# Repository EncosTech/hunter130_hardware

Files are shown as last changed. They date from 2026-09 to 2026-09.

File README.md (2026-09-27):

# Hunter V2 · 开源人形机器人硬件

> 快装快换，随心所造。

**Hunter V2** 是南京因克斯智能科技有限公司与桥介数物联合打造的开源人形机器人。因克斯负责硬件设计与制造，桥介数物负责软件开发，双方共同推进 Hunter 系列机器人的持续迭代。

本仓库 `hunter130_hardware` 提供 Hunter V2（EC H130-V2）的机械模型、电气资料、机器人描述文件和安装手册，供开发者开展结构研究、装配、仿真接入与二次开发。

## 项目亮点

- **第二代关节**：采用因克斯第二代关节模组，支持快速拆装，便于维护与更换。
- **25 个自由度**：覆盖躯干、双臂与双腿，为人形机器人的运动研究与开发提供硬件基础。
- **硬件与软件协作**：因克斯负责硬件，桥介数物负责部署与训练相关软件。
- **持续迭代**：延续 Hunter V1 的开源合作，继续更新 Hunter 系列机器人及配套资源。

## 基本参数

| 项目 | 规格 |
| --- | --- |
| 产品名称 | Hunter V2 |
| 硬件型号 | EC H130-V2 |
| 身高 | 130 cm |
| 整机重量 | 约 32 kg |
| 全身自由度 | 25 |
| 关节模组 | 因克斯第二代关节，支持快速拆装 |
| 硬件设计与制造 | 南京因克斯智能科技有限公司 |
| 软件开发 | 桥介数物 |

## 仓库内容

```text
hunter130_hardware/
├── Mechanical/                       # 机械模型与安装手册
│   ├── EC-H130-V2_装配体.STEP        # STEP 格式整机装配模型（Git LFS）
│   ├── EC-H130-V2_装配体.x_t         # Parasolid 格式整机装配模型（Git LFS）
│   └── EC H130-V2 产品安装手册.md
├── Electrical/                       # 电气资料
│   ├── Pcb/
│   │   ├── PMS/                      # PMS 板 PDF 与三维模型
│   │   ├── 胸腔电池安装板/            # 电池安装板 PDF 与三维模型
│   │   ├── 腿部电容板/                # 腿部电容板 PDF 与三维模型
│   │   └── 髋中心板/                  # 髋中心板 PDF 与三维模型
│   └── Wire/
│       ├── EC-H130线长.md             # 各部位线长、板卡与电阻要求
│       └── images/ec-h130-wire/       # 线束参考图片
├── URDF/                             # 机器人描述与网格资源
│   ├── EC-H130-V2_URDF.urdf
│   └── meshes/                       # STL 网格文件
├── LICENSE
└── README.md
```

| 资源 | 入口 | 内容 |
| --- | --- | --- |
| 安装手册 | [EC H130-V2 产品安装手册](Mechanical/EC%20H130-V2%20产品安装手册.md) | 装配注意事项、安装步骤、操作说明与物料清单 |
| 机械模型 | [STEP](Mechanical/EC-H130-V2_装配体.STEP) · [Parasolid](Mechanical/EC-H130-V2_装配体.x_t) | 两种格式的整机装配模型，均通过 Git LFS 下载 |
| 电气资料 | [Electrical/Pcb](Electrical/Pcb/) | PMS 板、胸腔电池安装板、腿部电容板和髋中心板的 PDF 与 STEP 文件 |
| 线束资料 | [EC-H130 线长](Electrical/Wire/EC-H130线长.md) | 各部位线长、电路板型号、电阻要求与线束参考图片 |
| 机器人描述 | [URDF](URDF/) | URDF 文件及其引用的 STL 网格资源 |

## 开始使用

### 下载完整模型

本仓库使用 [Git LFS](https://git-lfs.com/) 管理 STEP/STP、Parasolid（X_T/X_B）和 STL 模型，文件扩展名不区分大小写。请先安装 Git 和 Git LFS，再执行：

```bash
git lfs install
git clone https://github.com/EncosTech/hunter130_hardware.git
cd hunter130_hardware
git lfs pull
```

已有本地仓库时，在仓库目录执行 `git lfs install`、`git pull` 和 `git lfs pull`。使用 `git lfs ls-files` 可以查看由 LFS 管理的文件。

如果模型文件只有几行文本，并以 `version https://git-lfs.github.com/spec/v1` 开头，说明下载到的是 LFS 指针；请执行 `git lfs pull` 获取完整模型。GitHub 的 **Download ZIP** 是否包含模型原文件取决于仓库设置，建议使用上面的克隆方式。

### 使用资料

1. **了解结构与装配要求**：先阅读[安装手册](Mechanical/EC%20H130-V2%20产品安装手册.md)，了解装配流程、所需物料与安全操作要求。
2. **查看机械模型**：使用支持 STEP 或 Parasolid 的 CAD 工具打开 [Mechanical](Mechanical/) 中的模型。
3. **查看电气与线束资料**：按板卡类别查阅 [Electrical/Pcb](Electrical/Pcb/) 下的 PDF 与三维模型；线束制作与接线时，查阅 [EC-H130 线长](Electrical/Wire/EC-H130线长.md) 中的尺寸、板卡和电阻要求。
4. **接入仿真或可视化工具**：加载 [EC-H130-V2_URDF.urdf](URDF/EC-H130-V2_URDF.urdf)，并保留其与 `meshes/` 文件夹的相对位置。接入具体平台时，请按平台要求配置资源路径与控制接口。

## 软件与后续计划

本仓库聚焦硬件资料。部署程序与训练程序由桥介数物负责，作为配套软件开源内容持续更新；相关仓库链接将在公布后补充到此处。

后续计划兼容桥介 **RoboCraft AI** 平台，该项为规划内容。硬件资料与软件资源将随 Hunter 系列迭代持续完善。

## 反馈与贡献

欢迎通过 Issues 反馈资料问题、装配经验与改进建议，也欢迎提交 Pull Request 完善文档和设计资料。反馈时请注明硬件版本、相关文件路径，以及便于复现问题的说明或图片。

提交模型前，请在本地仓库执行 `git lfs install`。根目录的 `.gitattributes` 会自动将上述模型格式交给 LFS；按平常的 `git add`、`git commit`、`git push` 流程提交即可，推送时会同时上传 LFS 文件。新增其他大文件格式时，请先使用 `git lfs track` 配置追踪，并将更新后的 `.gitattributes` 一起提交。配置说明见 [GitHub 官方文档](https://docs.github.com/en/repositories/working-with-files/managing-large-files/configuring-git-large-file-storage)。

## 许可证

除另有说明的第三方材料外，本仓库由项目权利人提供的硬件设计文件、机器人描述文件及配套文档采用 **CERN Open Hardware Licence Version 2 – Strongly Reciprocal（CERN-OHL-S-2.0）** 授权。完整条款见 [LICENSE](LICENSE)。

SPDX-License-Identifier: CERN-OHL-S-2.0

允许依照许可证使用、复制、修改、制造和销售。对外分发相关设计或产品时，须履行许可证规定的完整源文件提供、声明保留和修改标注等义务；适用例外以许可证原文为准。

第三方材料遵循各自的许可证。本项目文档中的安全提示、产品使用说明和合规说明不构成对 CERN-OHL-S-2.0 授予权利的附加限制，也不赋予任何一方单方面更改该许可证的权利。

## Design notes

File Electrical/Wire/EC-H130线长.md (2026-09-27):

# EC-H130 线长

## 大腿

- 电源：200 mm。
- 信号：250 mm。

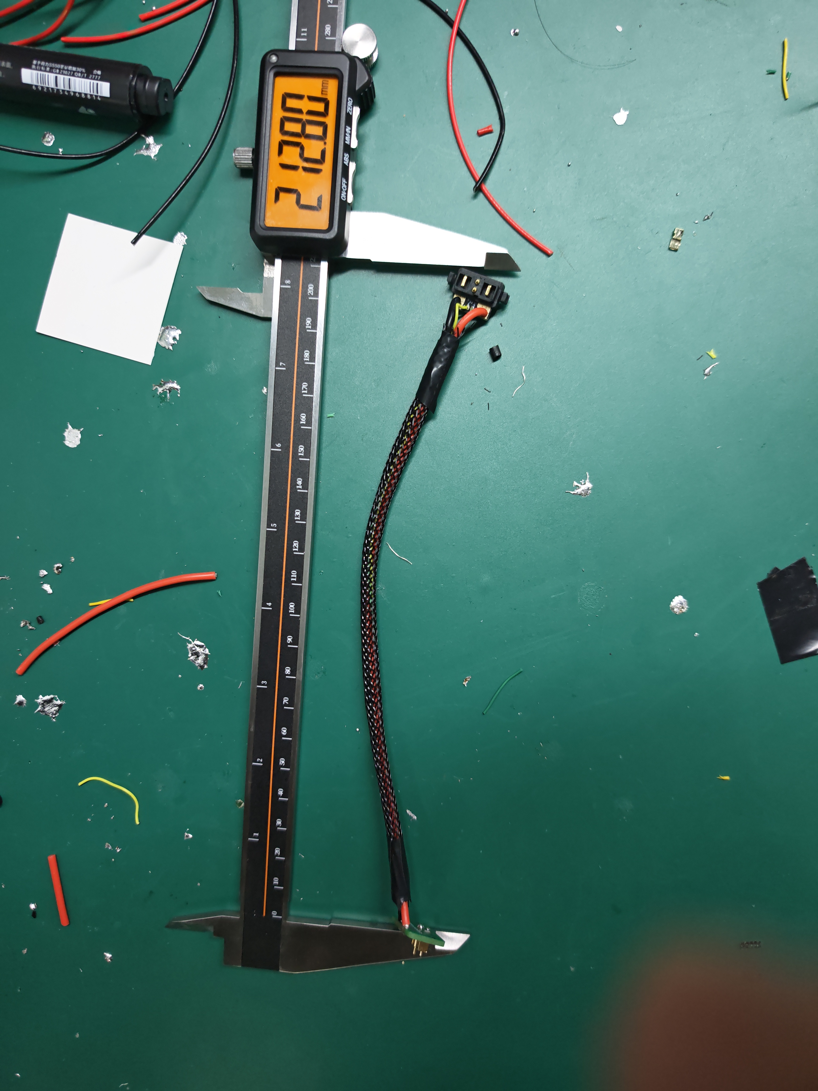
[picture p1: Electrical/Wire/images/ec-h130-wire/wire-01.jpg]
大腿线束


## 小臂

- 电源线：130 mm。

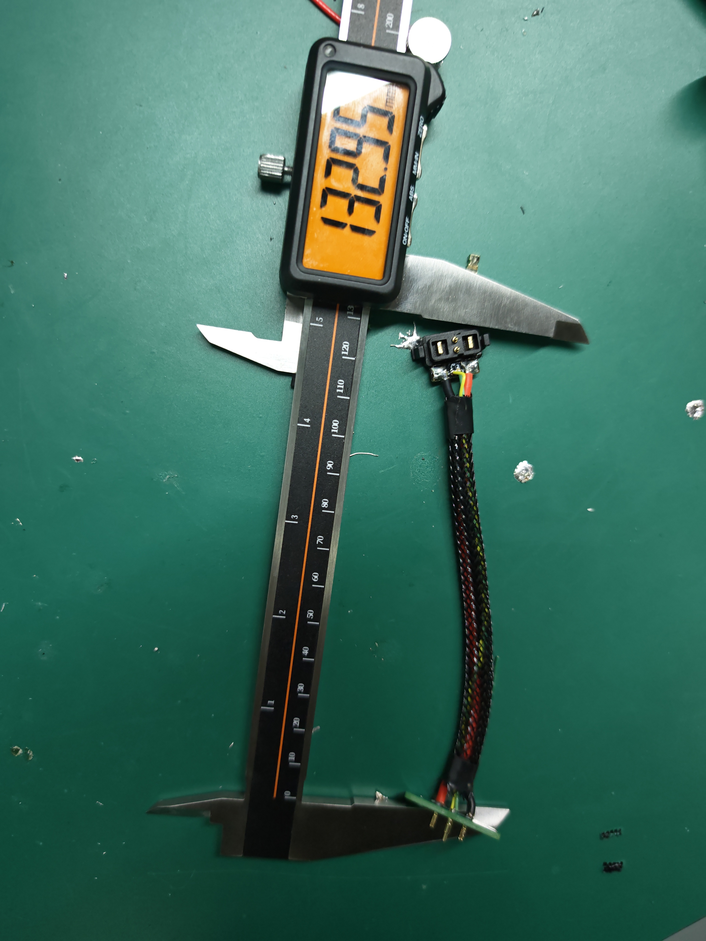
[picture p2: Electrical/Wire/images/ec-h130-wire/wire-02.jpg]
小臂线束


## 腿根

- 电路板：72xx。
- 线长：095 mm。

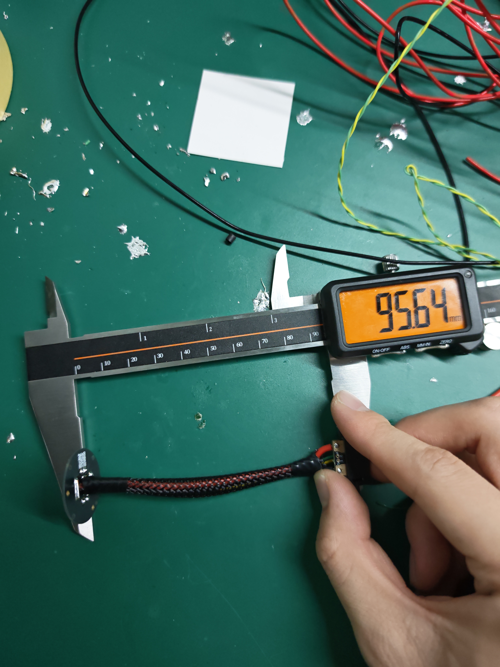
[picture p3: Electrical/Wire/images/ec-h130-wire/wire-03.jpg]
腿根线束


## 臂根

- 电路板：50xx。
- 线长：70 mm。

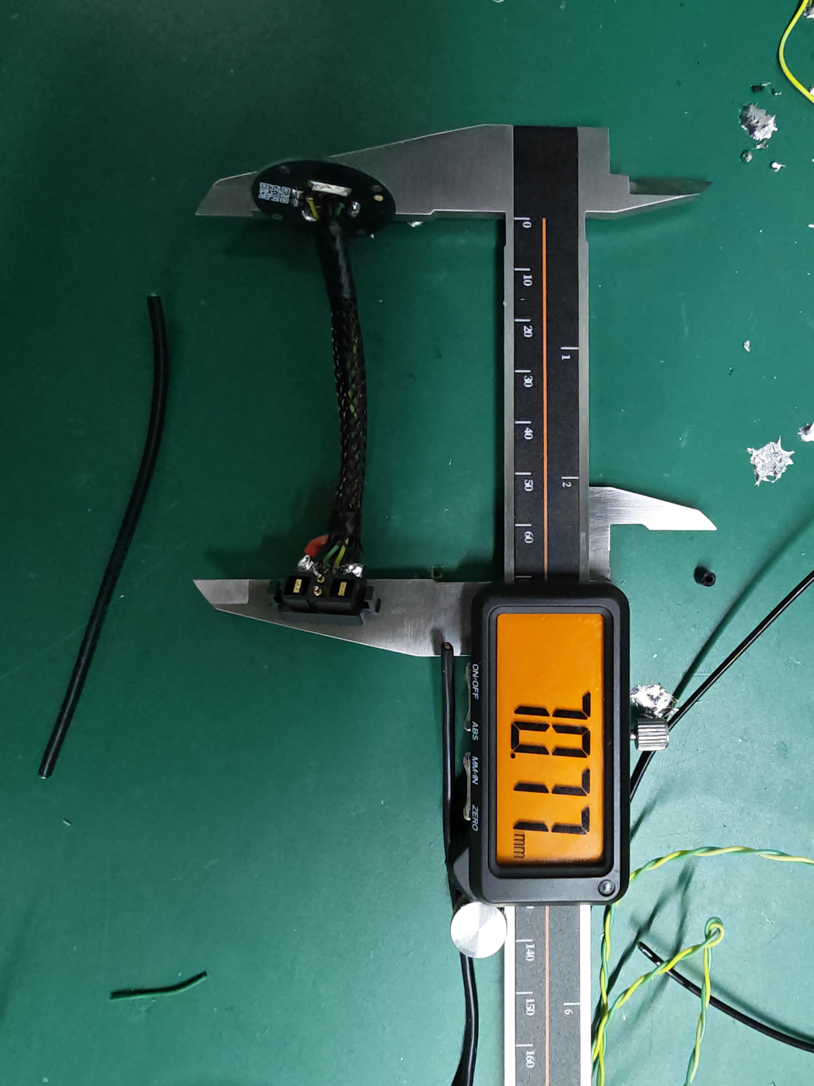
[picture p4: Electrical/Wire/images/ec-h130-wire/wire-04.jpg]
臂根线束


## 腿直角件 ×2

- 电路板：72xx。
- 线长：95 mm。

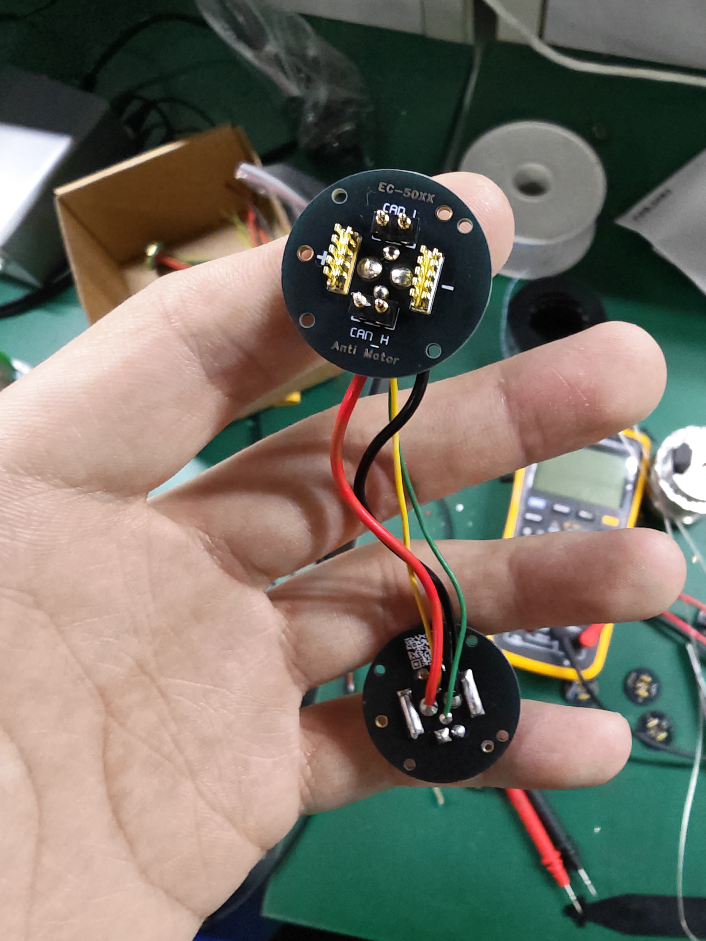
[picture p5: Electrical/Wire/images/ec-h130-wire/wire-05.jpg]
腿直角件线束


## 小腿双尾部

- 电源：200 mm。
- 信号线：203 mm。
- 需 120 Ω 电阻。

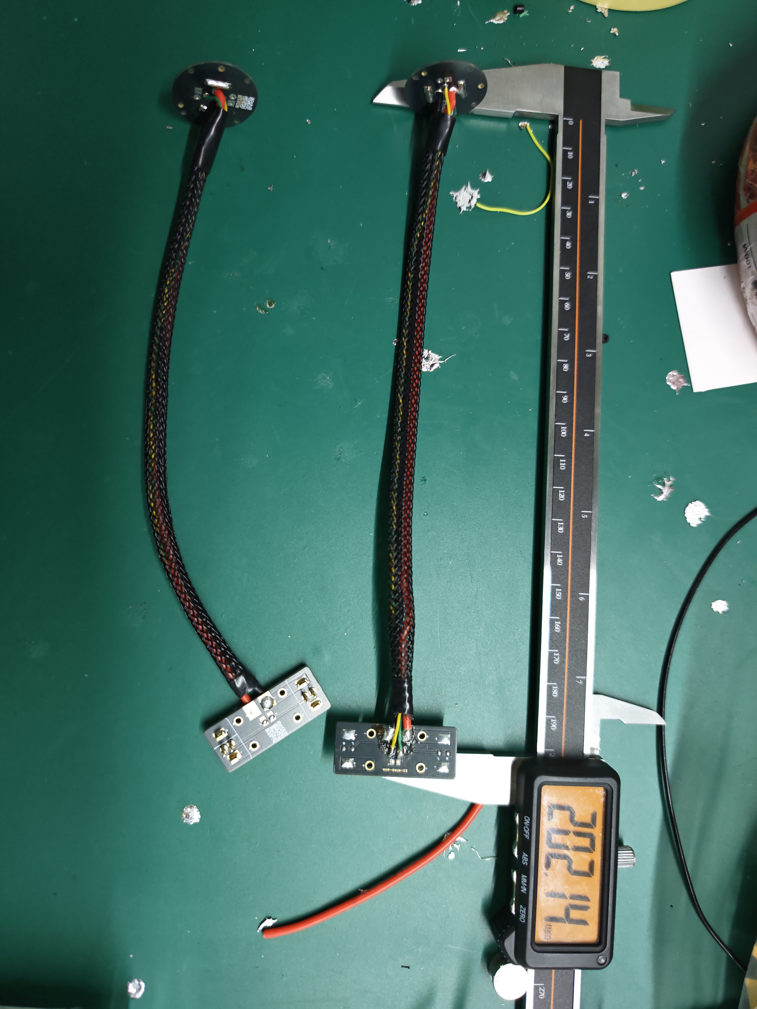
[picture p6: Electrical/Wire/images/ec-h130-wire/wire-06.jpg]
小腿双尾部线束


## 腰

- 线长：200 mm。
- 需 120 Ω 电阻。

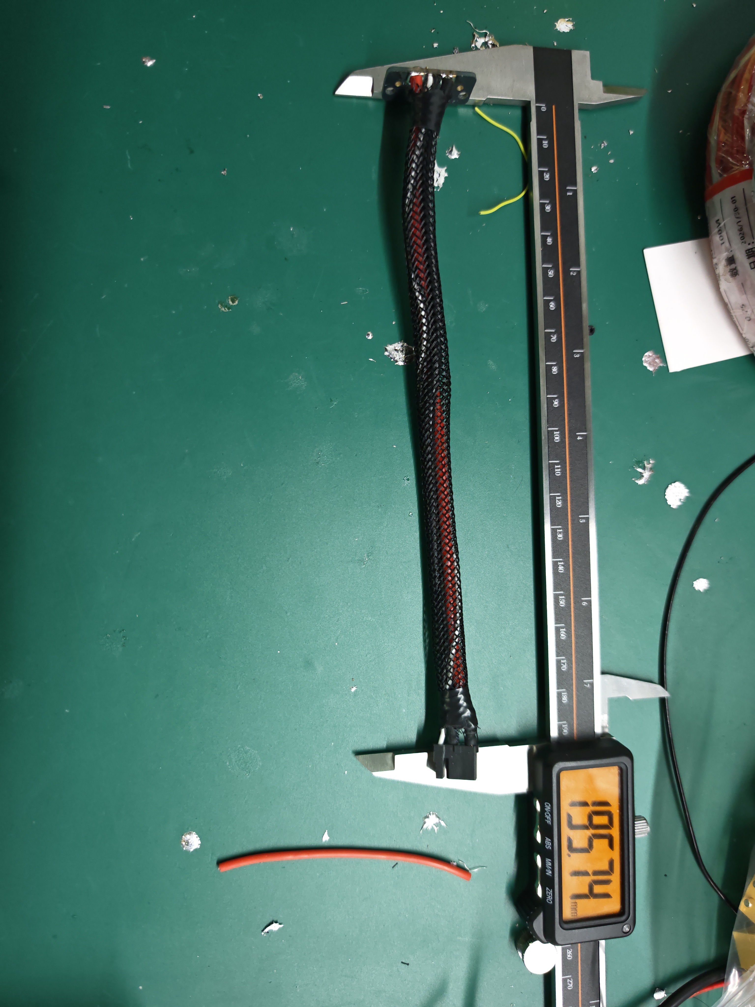
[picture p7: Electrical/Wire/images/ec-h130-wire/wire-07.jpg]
腰部线束


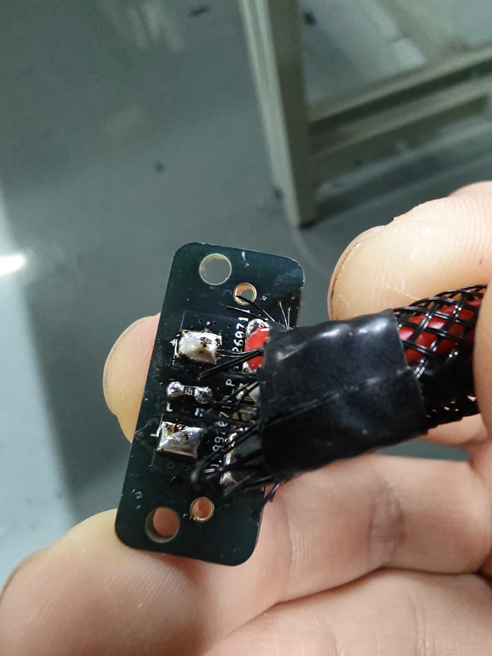
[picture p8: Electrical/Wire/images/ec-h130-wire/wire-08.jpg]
腰部接线板细节


## 左肩、右肩

- 线长：100 mm。
- 需 120 Ω 电阻。

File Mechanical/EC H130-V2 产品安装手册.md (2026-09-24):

# EC H130-V2 产品安装手册

> **开源许可证：CERN-OHL-S-2.0**  
> 本文档由项目权利人提供的内容采用 CERN Open Hardware Licence Version 2 – Strongly Reciprocal 授权，完整条款见仓库根目录的 [LICENSE](../LICENSE)。另有说明的第三方材料遵循各自许可证。  
> SPDX-License-Identifier: CERN-OHL-S-2.0  
> 本手册中的安全提示、产品使用说明、合规说明及“最终解释权”等表述，不构成对上述开源许可证授予权利的附加限制，也不赋予任何一方单方面更改该许可证的权利。适用法律规定的义务仍须遵守。

**EC H130-V2**

**产品安装手册**

南京因克斯智能科技有限公司

2026年9月

**目  录**

目录

1  安全及合规须知1

2  装配注意事项2

3  产品概述3

4  安装前置条件6

5  安装步骤7

6  安全操作指南17

附录A  主要零部件与辅料清单19

附录B  物料清单20

# 1  安全及合规须知

为避免违法行为、可能的伤害和损失，务必遵守以下各项规定：

1. 在使用本产品前，请务必仔细查阅本文档，以了解您的权益、责任以及安全事项；如未遵守可能导致财产损失或安全隐患。使用本产品即表示您已充分理解并接受本文件的所有条款，需严格按照规范操作，并对自身行为及相关后果负全责。

2. 本产品为非玩具类设备，不建议18岁以下人士使用。请防止儿童接触产品，在有儿童场景中操作时须特别谨慎。

3. 本产品不宜在人员密集区域使用，使用时需确保人员与机器距离保持在1米半径外。如因误操作对相关人员造成伤害或损失，南京因克斯智能科技有限公司不承担任何责任。

4. 本产品设计为接触地面使用，请勿在设备运动过程中抬起设备造成双腿离地。

5. 请勿在极端环境（如高温、低温、腐蚀性化学物质等）下使用本产品。因此类情况造成的设备问题，南京因克斯智能科技有限公司不承担任何责任。

6. 在正常使用条件下，因零部件自然磨损或电池老化导致的问题，不视为产品质量问题，南京因克斯智能科技有限公司对此不承担责任。

7. 本产品禁止用于任何危害国家安全的活动，包括但不限于恐怖主义支持、核设施、生化武器研发或大规模杀伤性武器的设计与使用等领域。

8. 您确认您未受任何贸易限制或制裁措施的影响，否则可能无法正常使用南京因克斯智能科技有限公司系列产品及服务。

9. 南京因克斯智能科技有限公司致力于确保产品在全球范围内合规。请遵守所在地区的法律法规，并注意相关合规要求。

10. 您需遵守适用地区的出口管制法律法规。

11. 您承诺将本产品用于正当用途，并同意接受本文件所有条款。

12. 在当地法律适用范围内，南京因克斯智能科技有限公司保留对本协议的最终解释权，并可能根据需要进行更新或调整。

注：现有手册基于当前 EC H130-V2 版本编制，因产品持续优化，后续批次的套件和文档可能存在微调，最新版本文档可在公司官网服务与支持页面查阅，最终解释权归属南京因克斯智能科技有限公司所有。

# 2  装配注意事项

## 2.1  工作台管理

### 2.1.1  分区摆放

（1）左侧：待装配物料区（仅放置当前工序所需物料）。

（2）中间：作业区（铺设防静电胶皮，保持清洁）。

（3）右侧：成品/半成品放置区。

### 2.1.2  异物防范

严禁在工作台上放置与生产无关的物品（如手机、水杯、钥匙），防止金属异物掉入产品内部造成短路。

## 2.2  个人防护装备标准

（1）防静电手套：接触所有电子元器件、电路板、摄像头模组时佩戴。

（2）丁腈手套：使用润滑脂、导热硅脂、螺纹胶、厌氧胶等化学品时佩戴。

（3）束发/着装强制：长发必须盘起并塞入工帽；严禁佩戴悬挂式首饰（项链、手链）；袖口需束紧。

## 2.3  核心安全作业规程

### 2.3.1  锂电池安全操作

本产品使用高能量密度锂电池组，操作不当极易引发火灾。

跌落处置：任何电池组一旦发生跌落（高度大于30cm）或受到剧烈撞击，严禁再次装机使用。必须立即贴上红色“待报废/观察”标签，并移至指定的防爆安全柜或沙箱中隔离观察24小时。

### 2.3.2  机械防夹与操作

（1）断电作业：关节的安装、调试与更换，必须在急停按下且断开电源的状态下进行。

（2）手动盘车：严禁将手指伸入关节活动的缝隙或限位槽内，防止关节因重力滑落或惯性闭合时造成手指挤压骨折。

（3）螺丝固定：拧平头螺丝时不宜用力过猛，以免造成滑丝。

### 2.3.3  化学品使用安全

（1）螺纹胶：仅涂抹于螺纹末端3—4牙处，严禁过量溢出污染塑料件（部分塑料遇螺纹胶会脆裂）。

（2）厌氧胶（如243）：用于螺钉防松，螺钉固定前按要求涂抹，注意控制用量。

（3）废弃物处理：沾染化学品的无尘布、棉签属于危险废弃物，必须丢弃至专门的黄色危废垃圾桶，严禁混入普通垃圾。

### 2.3.4  紧急响应流程

当发生异常情况（冒烟、起火、异响、人员受伤）时，严格遵循“停止—隔离—上报”流程。

电池/电路起火处置：

步骤一：立即按下总电源急停开关。

步骤二：人员迅速撤离至安全距离（大于3米），并大声示警。

步骤三：小火苗：使用干粉灭火器扑灭，严禁用水。

（4）大火：立即拨打火警电话并撤离车间。

# 3  产品概述

## 3.1  产品简介

EC H130-V2 是南京因克斯智能科技有限公司面向科研、教育以及展演场景推出的人形机器人平台。产品采用模块化关节模组与铝合金结构件设计，全身关节由多种规格的伺服模组驱动，覆盖躯干、腰部、双臂、髋部与双腿，结构紧凑，便于实验室调试、教学实验与工程验证。主要结构件采用铝合金加工，外观件通过3D打印快速成型，装配效率高、维护成本低。本手册依据产品当前版本的安装工序（SOP）编制，详细说明安装前置条件、安装步骤、检测方法与安全操作要求。

## 3.2 产品参数

| 无标题的项目 (2).jpg | **结构参数** |  |
| --- | --- | --- |
|  | 身高 | 130 cm |
|  | 自由度 | 25 |
|  | 体重 | 30kg |
|  | 结构件材质 | 航空铝+调制40cr |
|  | **电源与电池** |  |
|  | 电池类型 | 可充电锂离子电池 |
|  | 续航时长 | 3.5h（两块） |
|  | 标称电压 | 46.8V |
|  | 充电方式 | 充电器/cc-cv |
|  | BMS保护功能 | 限位/过流/过压保护 |

**3.3****安装说明**

在开始组装前，请根据下图电机ID布局，对所有电机进行ID分配与编码器校准；禁止大力敲击电机，防止损坏内部组件。



## 3.4  关节模组配置

EC H130-V2 全身共使用 25 个关节模组，配置如下表所示。

| **序号** | **模组型号** | **数量** | **用途说明** |
| --- | --- | --- | --- |
| 1 | EC-A5020-P2-17H-A | 6 | 手臂、肩部等关节 |
| 2 | EC-A5020-P2-17H-B | 8 | 手臂、腿部等关节 |
| 3 | EC-A7220-P2-22H-A | 4 | 大功率关节 |
| 4 | EC-A7220-P2-22H-B | 4 | 大功率关节 |
| 5 | EC-A7216-P2-22H-A | 1 | 躯干/腰部旋转关节 |
| 6 | EC-A4315-P2-36-V2.5 | 2 | 小关节 |

注：模组具体装配位置与功率分配以产品实际发货配置为准。

## 3.5  安装工序总览

本产品装配共包含30道工序，安装顺序如下表所示。后续章节按此顺序组织安装步骤。

| **工序号** | **工序名称** | **工序性质** |
| --- | --- | --- |
| 1 | 电机ID更新 | 关键工序 |
| 2 | 躯干1的安装 | 关键工序 |
| 3 | 躯干2的安装 | 常规工序 |
| 4 | 腰部1的安装 | 常规工序 |
| 5 | 腰部2的安装 | 常规工序 |
| 6 | 腰部3的安装 | 常规工序 |
| 7 | 腰部电机中心线材1 | 常规工序 |
| 8 | 腰部电机中心线材2 | 常规工序 |
| 9 | 腰部的检测 | 常规工序 |
| 10 | 大臂1的安装 | 常规工序 |
| 11 | 大臂2的安装 | 常规工序 |
| 12 | 小臂1的安装 | 常规工序 |
| 13 | 小臂2的安装 | 常规工序 |
| 14 | 手臂总装 | 常规工序 |
| 15 | 肩部的安装 | 常规工序 |
| 16 | 手臂总装检测 | 常规工序 |
| 17 | 髋部1的安装 | 常规工序 |
| 18 | 髋部2的安装 | 常规工序 |
| 19 | 大腿的连接（左右件） | 常规工序 |
| 20 | 大腿-髋部（左右件）的安装 | 常规工序 |
| 21 | 腿组合的安装 | 常规工序 |
| 22 | 小腿1的安装 | 常规工序 |
| 23 | 小腿2的安装 | 常规工序 |
| 24 | 脚的安装 | 常规工序 |
| 25 | 大小腿组合 | 常规工序 |
| 26 | 腰部电机中心线材1（线束加工） | 常规工序 |
| 27 | 腰部电机中心线材2（线束加工） | 常规工序 |
| 28 | 腰部电机中心线材3（电气接线） | 常规工序 |
| 29 | 腿组合检测 | 常规工序 |
| 30 | 零位校准 | 关键工序 |
| 31 | 运动测试 | 关键工序 |

# 4  安装前置条件

## 4.1  工具与辅料准备

| **类别** | **名称** | **用途** |
| --- | --- | --- |
| 工具 | 内六角螺丝刀（扭力按工艺要求） | 各规格螺钉紧固 |
| 工具 | 电烙铁 | 线材焊接 |
| 工具 | 万用表 | 绝缘与导通检测、电阻测量 |
| 工具 | 小锤/手压机 | 轴套、轴承、万向节压装 |
| 工具 | 斜口钳 | 编织网管修剪 |
| 工具 | Robot Setup 软件及连接电脑 | 电机ID设置、零位校准 |
| 辅料 | 243厌氧胶 | 螺钉防松（锁付前涂抹） |
| 辅料 | AB胶 | 轴套、销钉固定 |
| 辅料 | 螺纹胶 | 特定螺纹连接 |
| 辅料 | 醋酸胶带 | 线束包裹固定 |
| 辅料 | 3M编织网管 | 线束防护 |
| 辅料 | 热缩管 | 焊点绝缘 |
| 辅料 | 电工胶布 | 电路板绝缘 |
| 辅料 | 防静电手套、丁腈手套 | 个人防护 |

## 4.2  电机ID分配与更新

装配前必须对所有电机进行ID分配与刷新，确保电机与软件配置一一对应。

（1）按照机身标示序号刷新电机：连接模组与电脑，点击 Robot Setup 启动软件。

（2）打开界面后，点击“电机ID设置”，按照标示序号进行依次刷新。

（3）全部电机ID刷新完成后，检查各电机状态正常后进入后续装配。

注意：电机ID设置属于关键工序，直接影响整机通信与运动控制，操作人员必须经培训合格后方可上岗。

## 4.3  通用装配规范

以下规范适用于全部装配工序，装配过程中必须严格遵守：

（1）所有螺钉固定前需要涂抹243厌氧胶（特殊注明使用螺纹胶的工序除外）。

（2）对角锁螺钉，第一颗不锁紧，最后进行复锁；电机锁付时应对角固定。

（3）电机与加工件装配前，确认紧固件内部无杂质、铁屑，电机与紧固件平整度合格。

（4）模组与连接件对接时，须啮合到位、无缝隙。

（5）使用定位销定位时，销钉与孔位对应，定位销完全到位、无歪斜。

（6）电路板安装位置需贴电工胶布做绝缘的部位，不得遗漏。

（7）线束走线应沿预留走线凹槽布置，避免挤压与干涉。

（8）涉及焊接的工序，焊点应圆润、牢固、耐用，焊后按工序要求进行导通与绝缘检测。

# 5  安装步骤

## 5.1 上半身安装

  

STEP 1：将头部用6颗M3×6圆头内六角螺钉涂抹螺纹胶紧固，顶板用12颗M3×8圆头内六角螺钉涂抹螺纹胶紧固安装在驱赶部分。



STEP 2：取躯干左右肩板：用两颗5020A固定在左肩板、右肩板上的V型连接件，用50XX抱箍抱死肩板与模组，用两颗8颗M3×8圆头内六角螺钉涂抹螺纹胶紧固。

   

        STEP 3：取5020A-V型连接件连接肩部连接基座，用50XX抱箍抱死模组与连接件，再安装限位块并用两颗8颗M3×8圆头内六角螺钉涂抹螺纹胶紧固；取5020B，用8颗M3×8圆头内六角螺钉涂抹螺纹胶紧固，再用2颗内六角锥形沉头螺钉将限位块固定在肩部横滚连接基座上。

   

        STEP 4：取5020B端与L型连接件用4颗M3×8圆头内六角螺钉涂抹螺纹胶连接，再将5020A限位块安装好后用抱箍抱死L型直角件与5020A模组V型端。

    

        STEP 5：取5020A尾端与偏航连接件用抱箍抱死连接，再将5020B用8颗M3×8圆头内六角螺钉涂抹螺纹胶连接并将限位块用2颗内六角锥形沉头螺钉将限位块固定在偏航连接件上。



       STEP 6：取5020B电路板端与L型连接件连接，再将5020A与L型连接件另一端连接并用抱箍抱死，注意电路板与模组之间连接需要对准（左右手安装步骤相同，在此不作赘述）。



        STEP 7：取小臂与手部连接，用螺钉锁紧，再将5020A与小臂用抱箍抱死（需区分左右手）。



        STEP 8：底板安装φ5×8销钉，腰部限位块安装在槽内。将2个A4315电机安装在腰关节电机座上，用12颗螺钉固定。轴套涂抹AB胶放入髋关节电机座中，并放入腰部基准座中，在模组上销孔位置放置销钉φ4×6，再安装曲轴，黄铜轴套放入后用锤子将十字万向件敲进去，放入十字万向轴光轴φ7L35，再将丁字轴插入销轴一侧，用塞打螺丝M4-Φ5-H5表面涂抹AB胶固定丁字轴。取短连杆一侧用M3垫片加螺钉M3×6螺钉固定在曲轴上，另一侧塞入腰部基准座。将轴套放入间隙中，再放入关节轴承轴，用锤子敲打到位。用M3×10螺纹侧面锁死。取安装好的腰部与躯干，用M3×10螺丝涂抹螺纹胶，紧固底板，从中间孔洞走线。



STEP 9：取整个手臂与肩部连接，用抱箍抱死，将5020关节模组输出端用φ3×6销钉定位，再将模组输出端V型端面与大臂连接件V型端面贴合，用螺钉将抱箍锁死7216A用抱箍与腰部基座抱死，连接成为机器人上半身。

### 5.2  上半身总装检测

（1）将小臂末端用万用表打到欧姆档，将所有引脚（四排均检测）全部检测。

（2）用万用表一端放在立式插头正极（负极同理），另一端在外壳，测量通断，蜂鸣器不叫为正确；万用表一端放在立式插头正极，另一端放在手臂末端正极导通为正确（负极同理）。

（3）在黄线的中间位置焊接一个120欧的电阻，将万用表打开蜂鸣器、调至欧姆档，正负极为120欧姆即为正确数值。

## 5.2  下半身安装       

## 图片 19

STEP 1：取髋关节固定件在正反两面各安装4颗直径3.9的销钉，取2个快拆7220A与髋关节固定件进行安装，模组插口与电路板的插口对准安装取2对髋抱箍固定，用4颗M4×12螺钉进行紧固，注意抱箍时避让出锁螺钉的位置。

图片 20

STEP 2：腿部直角件组件上的快拆电机的接口对准大腿连接件上的电路板插线口位置，将两者安装到一起，电机与大腿连接件啮合到位无缝隙。取抱箍用2颗M4×12螺丝固定电机与大腿连接件。

图片 22

STEP 3：取7220B安装在髋关节偏航连接基座上，再用M4×6的螺丝涂抹螺纹胶固定，限位块用两颗内六角沉头螺钉M4×6固定。

图片 23

STEP 4：取小腿连接件确认无杂质、铁屑脏污后，取2个电机安装，插口朝下，各用8颗M3×8螺钉进行紧固。取2个曲轴各安装3颗φ4×8销钉。2个曲轴安装在腰关节电机座上，用12颗螺钉固定，翻转组件将电路板插入。

图片 24

STEP 5：将实心销插入脚踝，中间放入黄铜轴套，取足部方向安装卡簧，取带螺纹销中φ35m4双头螺纹钢销，有孔面依次穿过轴承座/足部万向节十字轴/轴承座，轴承座另一侧用销固定。

图片 25

STEP 6：将黄铜轴套放入小腿连接件中，插入实心销φ7×30，依次穿过小腿连接件、足部万向节十字轴、小腿连接件，卡簧固定，取长/短连杆先在两头分别安装在槽内。足底朝前情况下，带卡簧端朝外，左侧安装短连杆，右侧安装长连杆，再左右各用1颗垫片加M4×8螺钉进行对锁。将曲轴调整位置，用1个垫片、M3×6螺钉固定连杆上侧，用一根φ6×35的双头螺纹销压入脚底。

图片 26

STEP 7：取16个内六角扁平头螺钉M2.5×10固定鞋垫，翻转零件在底部用6颗螺钉M4×10进行紧固，将5×20实心销涂抹AB胶装入脚踝，2个轴套涂抹AB胶装进图示位置。

图片 29

STEP 8：在右腿上安装2颗3×6销钉，将大腿小腿组件进行对插，用6颗M4×20螺钉固定；固定完成后前后位置缝隙均匀。注意线束整理，整体靠近预留走线凹槽位置。

图片 30

STEP 9：取7220A模组与髋部连接件用抱箍抱死，装配时注意模组插口紧靠电路板方向，并与紧固件呈倾斜状态装配，销钉与孔对应，定位销完全到位、无歪斜。

             图片 31                           图片 32

STEP 10：将上半身和下半身用抱箍抱死，再将外壳打印件全部安装在对应孔位，如图所示。

## 5.3  电气接线

### 5.3.1  线束识别与XT30线材加工

（1）将万用表打成蜂鸣器档，依次测量腰部侧哪些线路属于本条腿（红绿黄黑线各一根），并拿标签纸标记好（分好左腿和右腿）；余下两根黄绿线标记为IMU。

（2）XT30线材的黑白端需裁剪与粗线长度一致，然后裁剪好热缩管并套入XT30线材内，将左腿的线材与XT30（2+2）线材进行焊接（右腿同理）。线材对应关系：红-红，粗黑-黑，白-黄，细黑-绿。

（3）将4PIN线沿尾部裁剪，将白线与黑线分别绕在一起并套上热缩管，与IMU的黄绿线进行焊接。线材对应关系：黑-绿，黄-白。

### 5.3.2  线束包裹

（1）将线材从洞口插入。

（2）将线的前端包住，插入编织网管内（长度大于露出来的线）。

（3）将网管的后端用醋酸胶带绑住（留裁剪），用斜口钳进行修剪。

（4）将修剪后的网管向后塞入线的出口处。

（5）将线网管的前端包住，保证线头露出以便进行后续操作。

（6）将十根线前端的硅胶剥开，露出内部铜丝。

### 5.3.3  电机与整机接线

（1）将腰部电源插入左侧电机下端。

（2）使用XT30连接线将左侧电机上端和右侧电机下端连接。

（3）将320mm的XT30连接线插入右侧电机的另一端，这根线命名为腰部连接线。

（4）将腰部连接线与腿部连接线一同插入槽内，并置于胸腔中。

（5）按插口进行线路连接（插入黑色插口），上方的乳白色口为对应的信号口，注意各线路一一对应（左臂、腰、左腿、右腿、右臂、电源、电池、5V）。

## 5.4  零位校准

（1）连接机器人与电脑，打开电脑点击 Robot Setup 按钮。

（2）点击“机器人整体配置”按钮，按照指示操作，完成机器人零位校准。

注意：零位校准前必须确认所有电机已完成ID设置与标定，校准完成后机器人各关节处于预设零位，方可进行后续调试。

# 6  安全操作指南

## 6.1  上电前检查

### 6.1.1  电源与电池核验

检查电池组当前电压。当电池电压低于产品规格书规定阈值时，请立即进行充电。严禁在欠压状态下运行，否则将触发欠压保护，导致机器人运行中行为异常或突然掉电跌倒。

### 6.1.2  机械结构核验

重点核对脚踝连杆、各关节抱箍、限位块的紧固状态。若脚踝连杆松动或未达到规定扭矩，将直接导致脚踝发力异常，机器人在调试阶段将无法正常站立并可能损坏结构件。

### 6.1.3  通讯链路核验

确认各关节模组与主控通讯正常，电机ID设置与软件配置一致，状态指示灯正常。

## 6.2  状态使能与零位初始化

（1）整机装配完成后，通过 Robot Setup 软件完成电机ID设置与机器人整体配置。

（2）执行零位校准，确认各关节处于预设零位。

（3）首次使能前，确认机器人处于安全姿态，人员与机器保持安全距离。

## 6.3  运行与应急处置

（1）运行过程中发生任何行为异常（如高频振荡、关节超速、失稳倾倒、异响），操作员应立即按下急停或断开电源。

（2）异常掉线排查：如果机器人在运行中发生非人为触发的突然失能（瘫软倒地），请保持现场状态。常见原因包括：算法层触发了设定的安全限幅（如关节超限、速度超限）；硬件层触发了过载、过热或欠压保护。

（3）日志留存：在断开主电源前，建议先导出错误日志，以便研发团队定位问题源头。

（4）紧急情况按第2.3.4节“停止—隔离—上报”流程处置。

# 附录A  主要零部件与辅料清单

下表汇总本产品装配过程中涉及的主要零部件与辅料，具体数量以各工序BOM为准。

| **类别** | **名称/规格** | **用途** |
| --- | --- | --- |
| 关节模组 | 5020A / 5020B / 7220A / 7220B / 7216A / 4315 | 全身关节驱动 |
| 结构件 | 前板、中板、肩板、右板、顶板、后板分隔板、把手、吊环 | 躯干结构 |
| 结构件 | 腰关节电机座、腰部基准座、底板、腰部限位块 | 腰部结构 |
| 结构件 | 曲轴、十字万向轴、丁字轴、轴套、短连杆、关节轴承轴 | 腰部传动 |
| 结构件 | 手臂直角连接件、大臂连接件、小臂连接件、50XX直角件 | 手臂结构 |
| 结构件 | 限位块（50抱箍/50直连/手臂旋转/前端盖/外圈YAW/72拖拽等） | 关节限位 |
| 结构件 | 髋关节固定件、髋抱箍、大腿连接件、髋部连接件、小腿连接件 | 髋腿结构 |
| 结构件 | 脚底板、轴承座、足底、脚底板连接件、腿部连杆（长/短） | 脚部结构 |
| 紧固件 | M1.6×4 / M2.5×4 / M2.5×6 / M3×6 / M3×8 / M3×10 / M3×12 / M3×16 / M4×8 / M4×10 / M4×12 / M4×18 / M4×20 / M5×8 / M5×16 / M6×12 等内六角圆柱头/沉头/平头螺钉 | 结构固定 |
| 紧固件 | 销钉（φ2.4×8、φ2.5×6、φ2.9×6、φ3×6、φ3×7、φ3×8、φ3.9、φ4×6、φ4×8、φ4×10、φ5×8、实心销φ7×30等） | 定位与连接 |
| 紧固件 | 塞打螺丝M4-Φ5-H5、无头螺丝M3×3/M3×5、双头螺纹销φ6×35、顶丝 | 传动与限位 |
| 电气件 | 电路板（躯干/手臂/髋部/腿部/IMU）、ethercat板、4PIN线、XT30连接线 | 信号与供电 |
| 辅料 | 243厌氧胶、AB胶、螺纹胶、醋酸胶带、3M编织网管、热缩管、电工胶布 | 装配辅料 |

注：本清单为安装手册汇总参考，各工序具体物料、规格与数量以公司发布的产品BOM与SOP为准。

# 附录B  物料清单

| **序号** | **文件名** | **数量** | **零件类型** | **材质** | **表面处理** | **配合备注** | **当前配置** | **包络尺寸** | **特征类型** |
| --- | --- | --- | --- | --- | --- | --- | --- | --- | --- |
| 1 | EC-H130-V2\_pelvis\_base | 1 | 加工件 | AL-7075 |  | 与7A电机配合，与半圆形PCB配合 | 默认 | 106.3\*88.0\*67.0 | 旋转特征件 |
| 2 | 转接固定连接件 | 1 | 加工件 | AL-7075 |  | 与加工件1配合 | 默认 | 54.0\*21.0\*12 | 拉伸特征件 |
| 3 | EC-H130-V2\_waist-roll-link\_base | 1 | 加工件 | AL-7075 |  | 与7A电机尾部配合，与加工件4，5配合 | 默认 | 88.0\*88.0\*45.5 |  |
| 4 | EC-H130-V2\_waist\_roll\_link\_固定安装 | 1 | 加工件 | AL-7075 |  | 与加工件3配合 | 默认 | 29\*18\*30.6 |  |
| 5 | EC-H130-waist-腰固定块 | 1 | 加工件 | AL-7075 |  | 与3，4组合件配合 | 默认 | 40.0\*33.9\*16.5.0 | 拉伸特征件 |
| 6 | EC-H130-V2\_waist-roll-link\_关节轴承轴 | 2 | 加工件 | 调制40Cr |  | 与12加工件配合，轴与径向球面轴承ge6c配合 | 默认 | 21.5\*8.5\*8.5 | 旋转特征件 |
| 7 | EC-H130-V2\_腰关节轴承轴套 | 2 | 加工件 | 调制40Cr |  | 与6号加工件配合 | 默认 | 7\*7\*4.3 |  |
| 8 | EC-H130-V2\_torso-link\_腰电机座 | 1 | 加工件 | AL-7075 |  | 与43电机配合，与9加工件配合，孔与圆柱销 Φ5x40配合，与平面推力滚针组合轴承rax705配合 | 默认 | 130.2\*82.1\*46.0 | 拉伸特征件 |
| 9 | EC-H130-V2\_torso-link\_并联限位挡块-220 | 2 | 加工件 | 调制40Cr |  | 与8号加工件配合 | 默认 | 54.8\*25.8\*2.0 | 拉伸特征件 |
| 10 | EC-H130-V2\_hip-yaw-link\_base \[right\] | 1 | 加工件 | AL-7075 |  | 与电机7A,7B配合，与长方形PCB配合 | right | 248.1\*92.2\*88.0 |  |
| 11 | EC-H130-V2\_hip-yaw-link\_base \[left\] | 1 | 加工件 | AL-7075 |  | 与电机7A,7B配合，与与长方形PCB配合配合 | left | 248.1\*92.2\*88.0 |  |
| 12 | EC-H130-V2\_hip-yaw-link\_膝外圈限位块\_205 \[left\] | 2 | 加工件 | 调制40Cr |  | 与加工件10，11配合 | 默认 | 91.0\*61.9\*3.0 | 拉伸特征件 |
| 13 | EC-H130-V2\_knee-link\_base \[left\] | 1 | 加工件 | AL-7075 |  | 与15号加工件配合，与43电机配合，与72xxPCB配合，孔与圆柱销 Φ5x30配合，与平面推力滚针组合轴承rax705配合 | left | 339.0\*64.2\*62.0 | 旋转特征件 |
| 14 | EC-H130-V2\_knee-link\_base \[right\] | 1 | 加工件 | AL-7075 |  | 与15号加工件配合，与43电机配合，与72xxPCB配合，孔与圆柱销 Φ5x30配合，与平面推力滚针组合轴承rax705配合 | right | 339.0\*64.2\*62.0 | 旋转特征件 |
| 15 | EC-H130-V2\_knee-link\_并联限位挡块\_220 | 4 | 加工件 | 调制40Cr |  | 与13，14号加工件配合 | 默认 | 59.9\*29.2\*2.5 | 拉伸特征件 |
| 16 | EC-H130-V2\_72XX抱箍输出法兰限位块 | 5 | 加工件 | 调制40Cr |  | 与17，18号加工件配合 | 默认 | 16.0\*15.5\*10.0 | 拉伸特征件 |
| 17 | EC-H130-V2\_hip-pitch-link\_base \[left\] | 1 | 加工件 | AL-7075 |  | 与7B电机配合，与72XXPCB配合，与16加工件配合 | left | 98.0\*94.3\*67.0 |  |
| 18 | EC-H130-V2\_hip-pitch-link\_base \[right\] | 1 | 加工件 | AL-7075 |  | 与7B电机配合，与72XXPCB配合，与16加工件配合 | right | 98.0\*94.3\*67.0 |  |
| 19 | EC-H130-V2\_hip-pitch-link\_roll限位块\_160 \[left\] | 2 | 加工件 | 调制40Cr |  | 与17，18号加工件配合 | 默认 | 73.0\*47.5\*3.0 | 拉伸特征件 |
| 20 | EC-H130-V2\_72XX直连输出法兰限位块 | 4 | 加工件 | 调制40Cr |  | 与21加工件配合 | 默认 | 14.5\*10.0\*6.0 | 拉伸特征件 |
| 21 | EC-H130-V2\_hip-roll-link\_base | 2 | 加工件 | AL-7075 |  | 与7A,7B配合，与72XXPCB配合，与20加工件配合 | 默认 | 94.5\*75.1\*67.0 |  |
| 22 | EC-H130-V2\_shoulder-pitch-link\_base \[left\] | 1 | 加工件 | AL-7075 |  | 与加工件24配合，与5A，5B电机配合，与50xxPCB配合 | left | 83.0\*80.5\*43.0 | 拉伸特征件 |
| 23 | EC-H130-V2\_shoulder-pitch-link\_base \[right\] | 1 | 加工件 | AL-7075 |  | 与加工件24配合，与5A，5B电机配合，与50xxPCB配合 | right | 83.0\*80.5\*43.0 | 拉伸特征件 |
| 24 | EC-H130-V2\_50XX抱箍输出法兰限位块 | 6 | 加工件 | 调制40Cr |  | 与加工件22，23配合 | 默认 | 11.5\*11.5\*6.0 | 拉伸特征件 |
| 25 | EC-H130-V2\_shoulder-pitch-link\_roll限位块\_160 | 4 | 加工件 | 调制40Cr |  | 与加工件22，23配合 | left | 46.0\*42.5\*2.0 | 拉伸特征件 |
| 26 | EC-H130-V2\_shoulder-yaw-link\_base \[right\] | 1 | 加工件 | AL-7075 |  | 与5A,5B电机配合,与25加工件配合，与长方形PCB配合 | right | 109.1\*63.2\*60.0 |  |
| 27 | EC-H130-V2\_shoulder-yaw-link\_base \[left\] | 1 | 加工件 | AL-7075 |  | 与5A,5B电机配合,与25加工件配合，与长方形PCB配合 | left | 109.1\*63.2\*60.0 |  |
| 28 | EC-H130-V2\_shoulder-roll-link\_base | 4 | 加工件 | AL-7075 |  | 与29加工件配合，与50xxPCB配合，与5B电机做配合 | 默认 | 65.3\*50.1\*43.0 |  |
| 29 | EC-H130-V2\_50XX直连输出法兰限位块 | 4 | 加工件 | 调制40Cr |  | 与28加工件配合 | 默认 | 9.9\*6.0\*6.0 | 拉伸特征件 |
| 30 | EC-H130-V2\_torso-link\_腰连杆-L60 | 2 | 加工件 | 调制40Cr |  | 孔与径向球面滑动轴承ge6c配合，与33加工件配合 | 默认 | 82.6\*34.9\*11.7 | 旋转特征件 |
| 31 | EC-H130-V2\_ankle-roll-link\_脚踝长连杆 | 2 | 加工件 | 调制40Cr |  | 孔与径向球面滑动轴承ge6c配合，与33加工件配合 | 默认 | 234.3\*22.6\*19.6 | 旋转特征件 |
| 32 | EC-H130-V2\_ankle-roll-link\_脚踝短连杆 | 2 | 加工件 | 调制40Cr |  | 孔与径向球面滑动轴承ge6c配合，与33加工件配合 | 默认 | 171.5\*22.7\*19.6 | 旋转特征件 |
| 33 | EC-H130-V2\_腰腿连杆焊接片 | 12 | 加工件 | 调制40Cr |  | 与30，31，32加工件配合 | 默认 | 15\*15\*1 |  |
| 34 | EC-H130-V2\_ankle-roll-link\_base | 2 | 加工件 | AL-7075 |  | 下孔与平面推力滚针组合轴承rax705装配，上孔与圆柱销 Φ6x30配合 | 默认 | 52.0\*42.7\*30.0 | 拉伸特征件 |
| 35 | EC-H130\_ankle-roll\_足底 | 2 | 加工件 | AL-7075 |  | 与加工件34配合 | 默认 | 198.0\*70.0\*8.0 | 拉伸特征件 |
| 36 | EC-H130-V2\_72XX前端盖限位块 | 5 | 加工件 | 调制40Cr |  | 与7A电机配合 | 默认 | 20.6\*20.6\*8.0 | 拉伸特征件 |
| 37 | EC-H130-V2\_50XX前端盖限位块 | 6 | 加工件 | 调制40Cr |  | 与5A电机配合 | 默认 | 13.6\*11.3\*5.2 | 拉伸特征件 |
| 38 | EC-H130-V2\_knee-link\_50XX曲轴 | 4 | 加工件 | 调制40Cr |  | 与43电机配合，轴与径向球面轴承ge6c配合 | 默认 | 51.6\*49.6\*19.0 | 拉伸特征件 |
| 39 | EC-H130-V2\_waist-pitch-link\_base | 1 | 加工件 | 调制40Cr |  | 轴与平面推力滚针组合轴承rax705配合，孔与内螺纹m4圆柱销 Φ5x40配合 | 默认 | 40.0\*18.5\*18.0 | 旋转特征件 |
| 40 | EC-H130\_4315曲轴 | 2 | 加工件 | 调制40Cr |  | 与43电机配合，轴与径向球面轴承ge6c配合 | 默认 | 49.9\*38.3\*18.5 | 拉伸特征件 |
| 41 | EC-H130-V2\_ankle-pitch-link\_base | 2 | 加工件 | 调制40Cr |  | 孔与圆柱销 Φ5x30配合 | 默认 | 38.2\*18.5\*16.3 | 拉伸特征件 |
| 42 | EC-H130-V2\_50XX尾部抱箍，固定端 | 4 | 加工件 | AL-7075 |  | 与5A,5B电机和26，27加工件配合 | 默认 | 74.0\*37.0\*14.0 | 旋转特征件 |
| 46 | EC-H130-V2\_50XX尾部抱箍，螺纹端 | 4 | 加工件 | AL-7075 |  | 与5A,5B电机和26，27加工件配合 | 默认 | 74.0\*37.0\*14.0 | 旋转特征件 |
| 43 | EC-H130-V2\_50XX输出法兰抱箍 | 6 | 加工件 | AL-7075 |  | 与5A和22，23加工件配合 | 默认 | 60.0\*30.0\*8.0 | 旋转特征件 |
| 47 | EC-H130-V2\_50XX输出法兰抱箍，螺纹端 | 6 | 加工件 | AL-7075 |  | 与5A和22，23加工件配合 | 默认 | 60.0\*30.0\*8.0 | 旋转特征件 |
| 44 | EC-H130-V2\_72XX输出法兰抱箍 | 5 | 加工件 | AL-7075 |  | 与7A，17，18加工件配合 | 默认 | 88.0\*44.0\*9.0 | 旋转特征件 |
| 48 | EC-H130-V2\_72XX输出法兰抱箍，螺纹端 | 5 | 加工件 | AL-7075 |  | 与7A17，18加工件配合 | 默认 | 88.0\*44.0\*9.0 | 旋转特征件 |
| 45 | EC-H130-V2\_72XX尾部抱箍 | 5 | 加工件 | AL-7075 |  | 与7A和1加工件配合 | 默认 | 104.0\*52.0\*15.0 | 旋转特征件 |
| 49 | EC-H130-V2\_72XX尾部抱箍，螺纹端 | 5 | 加工件 | AL-7075 |  | 与7A和1加工件配合 | 默认 | 104.0\*52.0\*15.0 | 旋转特征件 |

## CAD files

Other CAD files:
Electrical/Pcb/胸腔电池安装板/3D_胸腔电池安装板.step
Electrical/Pcb/腿部电容板/3D_腿部电容板_1.step
Electrical/Pcb/髋中心板/3D_130髋中心板.step
Mechanical/EC-H130-V2_装配体.STEP
URDF/meshes/left_wrist_roll_link_hand.STL
Electrical/Pcb/腿部电容板/3D_腿部电容板_2.step
URDF/meshes/left_knee_link.STL
URDF/meshes/right_hip_pitch_link.STL
URDF/meshes/right_ankle_roll_link.STL
URDF/meshes/right_knee_link.STL
URDF/meshes/waist_roll_link.STL
URDF/meshes/left_shoulder_yaw_link.STL
URDF/meshes/left_ankle_pitch_link.STL
URDF/meshes/left_shoulder_pitch_link.STL
URDF/meshes/right_hip_roll_link.STL
URDF/meshes/left_shoulder_roll_link.STL
URDF/meshes/right_shoulder_roll_link.STL
URDF/meshes/right_elbow_link.STL
Mechanical/EC-H130-V2_装配体.x_t
URDF/meshes/left_ankle_roll_link.STL
URDF/meshes/left_elbow_link.STL
URDF/meshes/left_hip_pitch_link.STL
URDF/meshes/left_hip_roll_link.STL
URDF/meshes/left_hip_yaw_link.STL
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

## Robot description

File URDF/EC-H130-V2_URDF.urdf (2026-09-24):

<?xml version="1.0" encoding="utf-8"?>
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
<robot name="EC-H130-V2_URDF">
  <link name="pelvis">
    <inertial>
      <origin xyz="-0.00005706 0.00001218 0.00272097" rpy="0 0 0" />
      <mass value="2.85330418" />
      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
    </inertial>
    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
  </link>
  <link name="left_hip_pitch_link">
    <inertial>
      <origin xyz="-0.00154712 0.04555177 -0.01331714" rpy="0 0 0" />
      <mass value="1.45048593" />
      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
    </inertial>
    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
  </link>
  <joint name="left_hip_pitch_joint" type="revolute">
    <origin xyz="0 0.0719 0" rpy="0 0 0" />
    <parent link="pelvis" />
    <child link="left_hip_pitch_link" />
    <axis xyz="0 1 0" />
    <limit lower="-2.7925268" upper="2.7925268" effort="150" velocity="27.75" />
  </joint>
  <link name="left_hip_roll_link">
    <inertial>
      <origin xyz="0.01766029 0 -0.03832869" rpy="0 0 0" />
      <mass value="0.32712694" />
      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
    </inertial>
    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
  </link>
  <joint name="left_hip_roll_joint" type="revolute">
    <origin xyz="0 0.0502 -0.015" rpy="0 0 0" />
    <parent link="left_hip_pitch_link" />
    <child link="left_hip_roll_link" />
    <axis xyz="1 0 0" />
    <limit lower="-0.5235988" upper="2.9670597" effort="150" velocity="27.75" />
  </joint>
  <link name="left_hip_yaw_link">
    <inertial>
      <origin xyz="0.00102498 -0.00744857 -0.14299393" rpy="0 0 0" />
      <mass value="2.93111837" />
      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
    </inertial>
    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
  </link>
  <joint name="left_hip_yaw_joint" type="revolute">
    <origin xyz="0 0 -0.0669" rpy="0 0 0" />
    <parent link="left_hip_roll_link" />
    <child link="left_hip_yaw_link" />
    <axis xyz="0 0 1" />
    <limit lower="-2.7925268" upper="2.7925268" effort="150" velocity="27.75" />
  </joint>
  <link name="left_knee_link">
    <inertial>
      <origin xyz="0.01590759 0.00298135 -0.11310658" rpy="0 0 0" />
      <mass value="1.46833842" />
      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
    </inertial>
    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
  </link>
  <joint name="left_knee_joint" type="revolute">
    <origin xyz="0 0 -0.2531" rpy="0 0 0" />
    <parent link="left_hip_yaw_link" />
    <child link="left_knee_link" />
    <axis xyz="0 1 0" />
    <limit lower="-0.0872665" upper="2.6179939" effort="150" velocity="27.75" />
  </joint>
  <link name="left_ankle_pitch_link">
    <inertial>
      <origin xyz="0.00013764 0.00000000 -0.00772773" rpy="0 0 0" />
      <mass value="0.02587791" />
      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
    </inertial>
    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
  </link>
  <joint name="left_ankle_pitch_joint" type="revolute">
    <origin xyz="0 0 -0.3" rpy="0 0 0" />
    <parent link="left_knee_link" />
    <child link="left_ankle_pitch_link" />
    <axis xyz="0 1 0" />
    <limit lower="-0.8726646" upper="0.5235988" effort="80" velocity="27.25" />
  </joint>
  <link name="left_ankle_roll_link">
    <inertial>
      <origin xyz="0.02007518 0.00050191 0.00982334" rpy="0 0 0" />
      <mass value="0.51466722" />
      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
    </inertial>
    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
  </link>
  <joint name="left_ankle_roll_joint" type="revolute">
    <origin xyz="0 0 -0.015" rpy="0 0 0" />
    <parent link="left_ankle_pitch_link" />
    <child link="left_ankle_roll_link" />
    <axis xyz="1 0 0" />
    <limit lower="-0.2617994" upper="0.2617994" effort="38" velocity="57.37" />
  </joint>
  <link name="right_hip_pitch_link">
    <inertial>
      <origin xyz="-0.00154712 -0.04555177 -0.01331714" rpy="0 0 0" />
      <mass value="1.45048593" />
      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
    </inertial>
    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
  </link>
  <joint name="right_hip_pitch_joint" type="revolute">
    <origin xyz="0 -0.0719 0" rpy="0 0 0" />
    <parent link="pelvis" />
    <child link="right_hip_pitch_link" />
    <axis xyz="0 1 0" />
    <limit lower="-2.7925268" upper="2.7925268" effort="150" velocity="27.75" />
  </joint>
  <link name="right_hip_roll_link">
    <inertial>
      <origin xyz="0.01766029 0 -0.03832869" rpy="0 0 0" />
      <mass value="0.32712694" />
      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
    </inertial>
    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
  </link>
  <joint name="right_hip_roll_joint" type="revolute">
    <origin xyz="0 -0.0502 -0.015" rpy="0 0 0" />
    <parent link="right_hip_pitch_link" />
    <child link="right_hip_roll_link" />
    <axis xyz="1 0 0" />
    <limit lower="-2.9670597" upper="0.5235988" effort="150" velocity="27.75" />
  </joint>
  <link name="right_hip_yaw_link">
    <inertial>
      <origin xyz="0.00102498 0.00744857 -0.14299393" rpy="0 0 0" />
      <mass value="2.93111837" />
      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
    </inertial>
    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
  </link>
  <joint name="right_hip_yaw_joint" type="revolute">
    <origin xyz="0 0 -0.0669" rpy="0 0 0" />
    <parent link="right_hip_roll_link" />
    <child link="right_hip_yaw_link" />
    <axis xyz="0 0 1" />
    <limit lower="-2.7925268" upper="2.7925268" effort="150" velocity="27.75" />
  </joint>
  <link name="right_knee_link">
    <inertial>
      <origin xyz="0.01590759 -0.00298135 -0.11310658" rpy="0 0 0" />
      <mass value="1.46833842" />
      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
    </inertial>
    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
  </link>
  <joint name="right_knee_joint" type="revolute">
    <origin xyz="0 0 -0.2531" rpy="0 0 0" />
    <parent link="right_hip_yaw_link" />
    <child link="right_knee_link" />
    <axis xyz="0 1 0" />
    <limit lower="-0.0872665" upper="2.6179939" effort="150" velocity="27.75" />
  </joint>
  <link name="right_ankle_pitch_link">
    <inertial>
      <origin xyz="0.00013764 0.00000000 -0.00772773" rpy="0 0 0" />
      <mass value="0.02587791" />
      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
    </inertial>
    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
  </link>
  <joint name="right_ankle_pitch_joint" type="revolute">
    <origin xyz="0 0 -0.3" rpy="0 0 0" />
    <parent link="right_knee_link" />
    <child link="right_ankle_pitch_link" />
    <axis xyz="0 1 0" />
    <limit lower="-0.8726646" upper="0.5235988" effort="80" velocity="27.25" />
  </joint>
  <link name="right_ankle_roll_link">
    <inertial>
      <origin xyz="0.02007518 -0.00050191 0.00982334" rpy="0 0 0" />
      <mass value="0.51466722" />
      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
    </inertial>
    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
  </link>
  <joint name="right_ankle_roll_joint" type="revolute">
    <origin xyz="0 0 -0.015" rpy="0 0 0" />
    <parent link="right_ankle_pitch_link" />
    <child link="right_ankle_roll_link" />
    <axis xyz="1 0 0" />
    <limit lower="-0.2617994" upper="0.2617994" effort="38" velocity="57.37" />
  </joint>
  <link name="waist_yaw_link">
    <inertial>
      <origin xyz="-0.00061769 0 0.03975727" rpy="0 0 0" />
      <mass value="1.40522272" />
      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
    </inertial>
    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
  </link>
  <joint name="waist_yaw_joint" type="revolute">
    <origin xyz="0 0 0.0607" rpy="0 0 0" />
    <parent link="pelvis" />
    <child link="waist_yaw_link" />
    <axis xyz="0 0 1" />
    <limit lower="-2.0071286" upper="3.577925" effort="150" velocity="27.75" />
  </joint>
  <link name="waist_roll_link">
    <inertial>
      <origin xyz="0 0 0" rpy="0 0 0" />
      <mass value="0.03850117" />
      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
    </inertial>
    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
  </link>
  <joint name="waist_roll_joint" type="revolute">
    <origin xyz="0 0 0.0918" rpy="0 0 0" />
    <parent link="waist_yaw_link" />
    <child link="waist_roll_link" />
    <axis xyz="1 0 0" />
    <limit lower="-0.5235988" upper="0.5235988" effort="140" velocity="12.22" />
  </joint>
  <link name="torso_link">
    <inertial>
      <origin xyz="0 0 0.14580503" rpy="0 0 0" />
      <mass value="7.19060687" />
      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
    </inertial>
    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
  </link>
  <joint name="waist_pitch_joint" type="revolute">
    <origin xyz="0 0 0" rpy="0 0 0" />
    <parent link="waist_roll_link" />
    <child link="torso_link" />
    <axis xyz="0 1 0" />
    <limit lower="-0.5235988" upper="0.5235988" effort="112.5" velocity="15.21" />
  </joint>
  <link name="left_shoulder_pitch_link">
    <inertial>
      <origin xyz="-0.00766857 0.03242941 -0.01110023" rpy="0 0 0" />
      <mass value="0.58842994" />
      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
    </inertial>
    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
  </link>
  <joint name="left_shoulder_pitch_joint" type="revolute">
    <origin xyz="0 0.14421 0.24201" rpy="0.2618 0 0" />
    <parent link="torso_link" />
    <child link="left_shoulder_pitch_link" />
    <axis xyz="0 1 0" />
    <limit lower="-3.577925" upper="2.0071286" effort="30" velocity="36.34" />
  </joint>
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

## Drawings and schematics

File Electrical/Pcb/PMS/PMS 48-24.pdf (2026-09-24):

## NMOS

环路

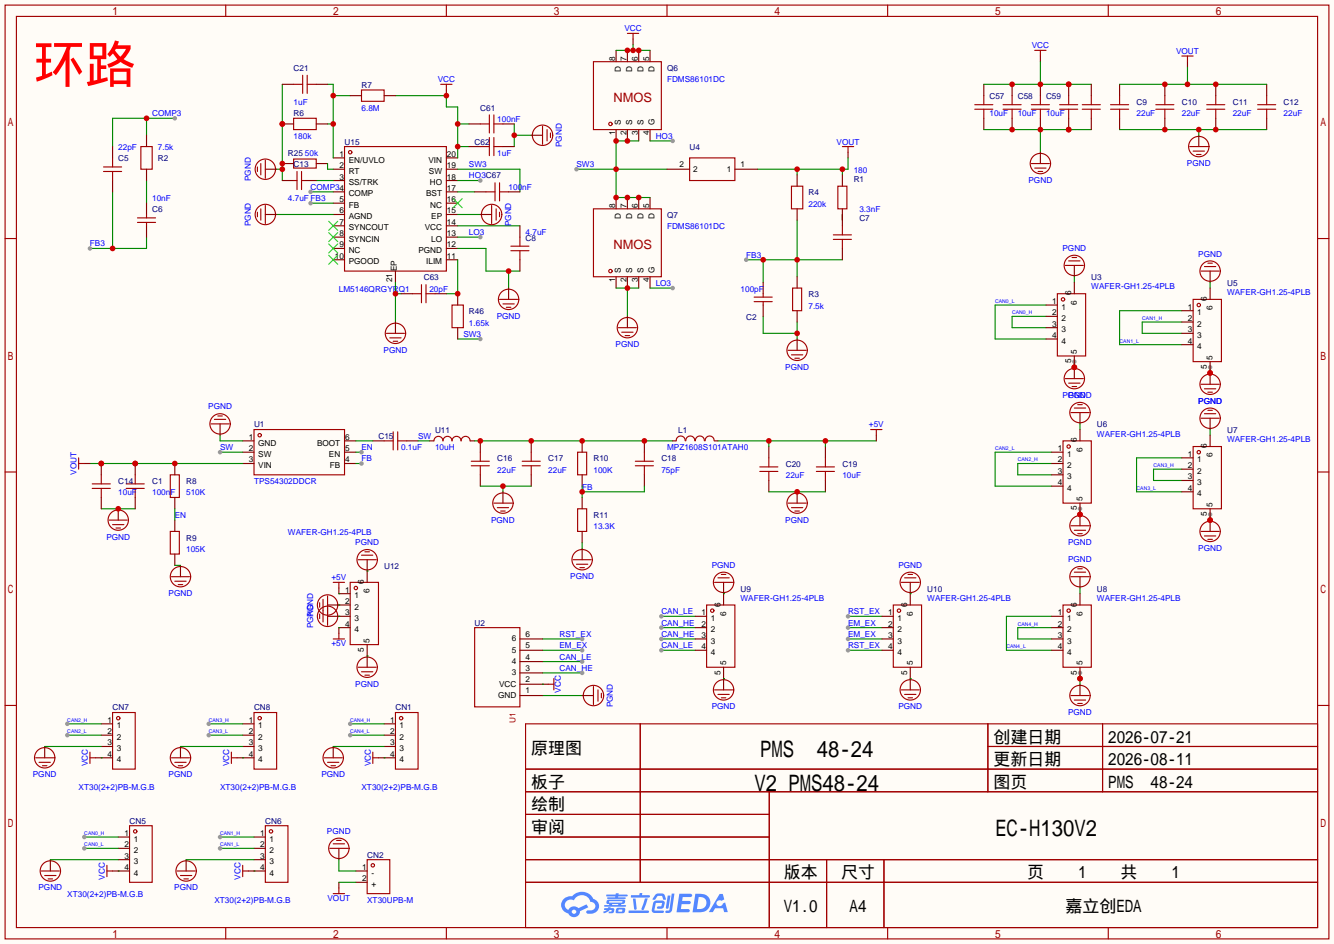
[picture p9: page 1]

原理图 | PMS 48-24 | 创建日期 | 2026-07-21

更新日期 | 2026-08-11

板子 | V2 PMS48-24 | 图页 | PMS 48-24
绘制 | | EC-H130V2
审阅

V1.0 | A4 | 嘉立创EDA

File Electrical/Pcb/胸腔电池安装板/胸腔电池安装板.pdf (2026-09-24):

1

1

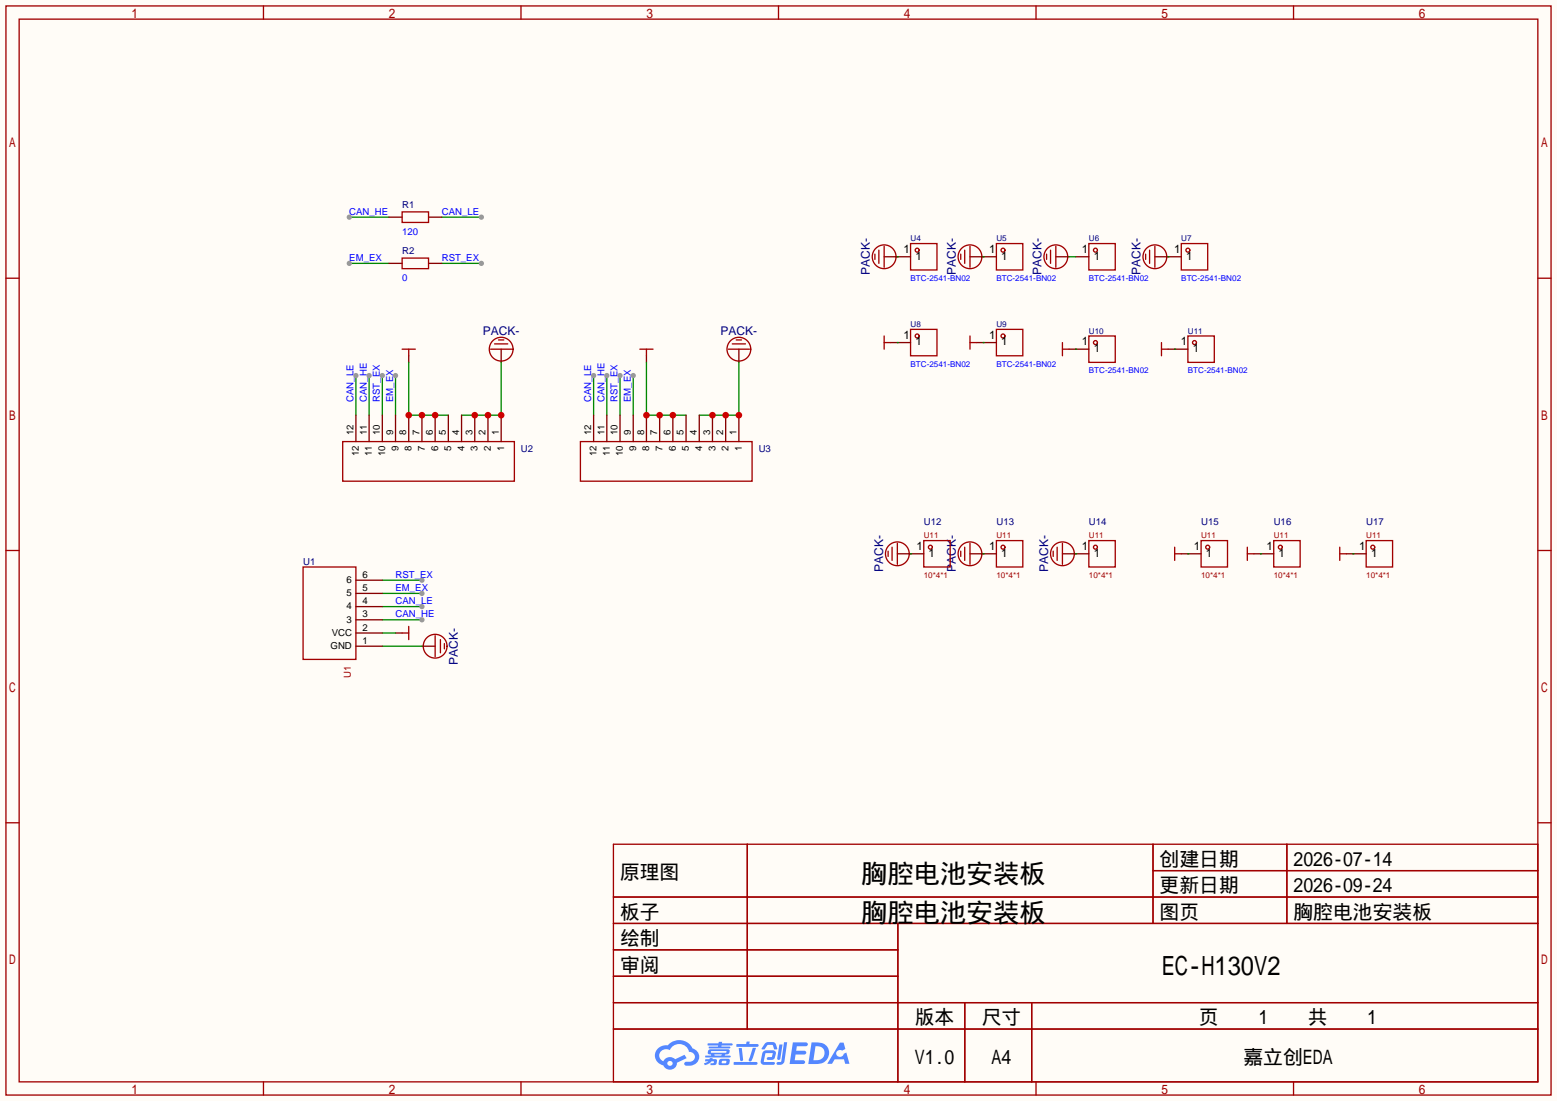
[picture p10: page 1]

原理图 | 胸腔电池安装板 | 创建日期 | 2026-07-14

更新日期 | 2026-09-24

绘制 | EC-H130V2
审阅

V1.0 | A4 | 嘉立创EDA

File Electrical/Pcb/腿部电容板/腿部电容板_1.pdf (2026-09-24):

# CAN1_L VCC VCC

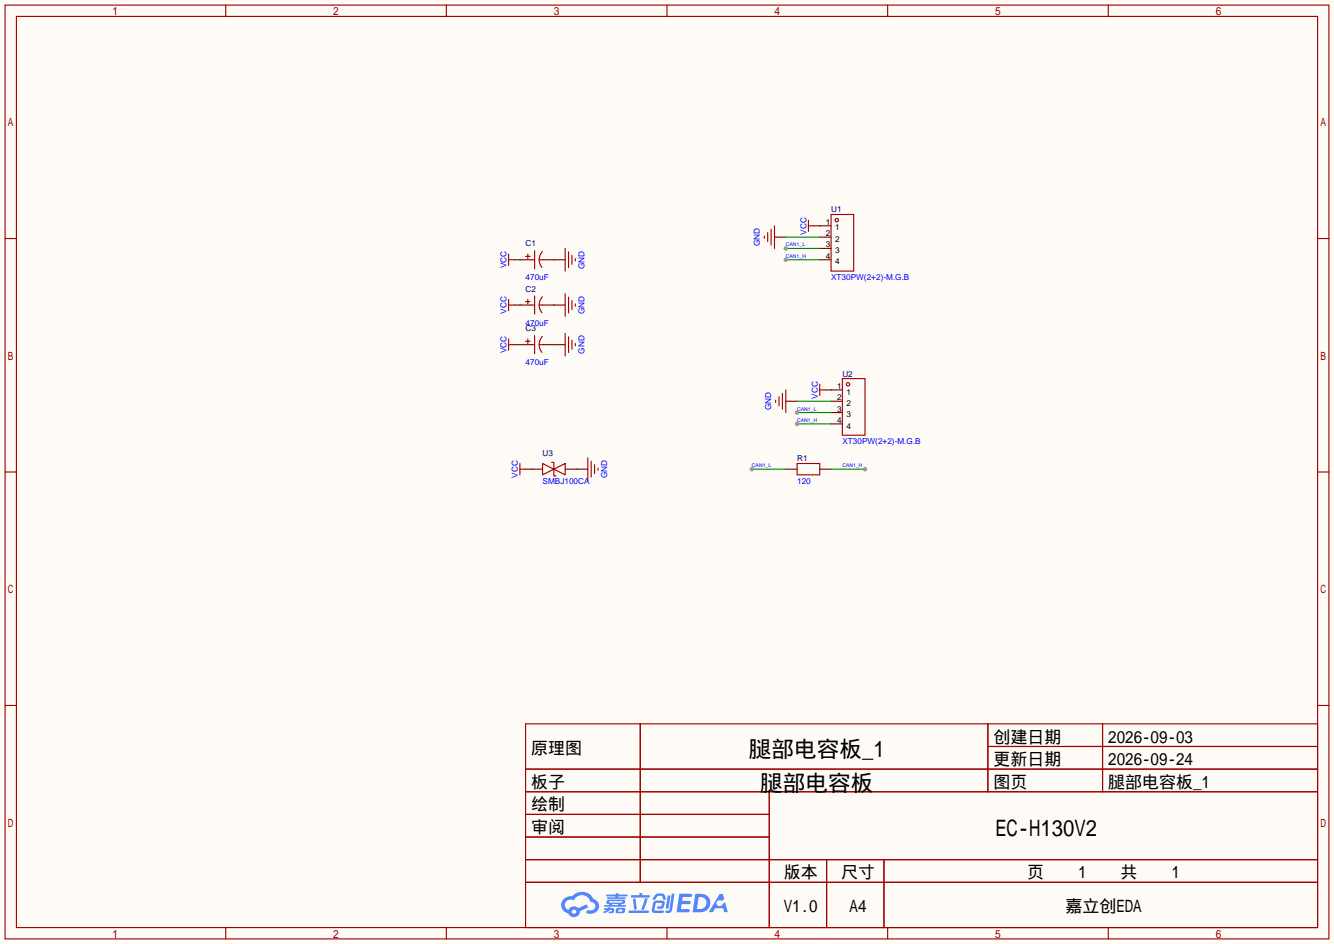
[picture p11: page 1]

原理图 | 腿部电容板_1 | 创建日期 | 2026-09-03

更新日期 | 2026-09-24

板子 | 腿部电容板 | 图页 | 腿部电容板_1
绘制 | | EC-H130V2
审阅

V1.0 | A4 | 嘉立创EDA

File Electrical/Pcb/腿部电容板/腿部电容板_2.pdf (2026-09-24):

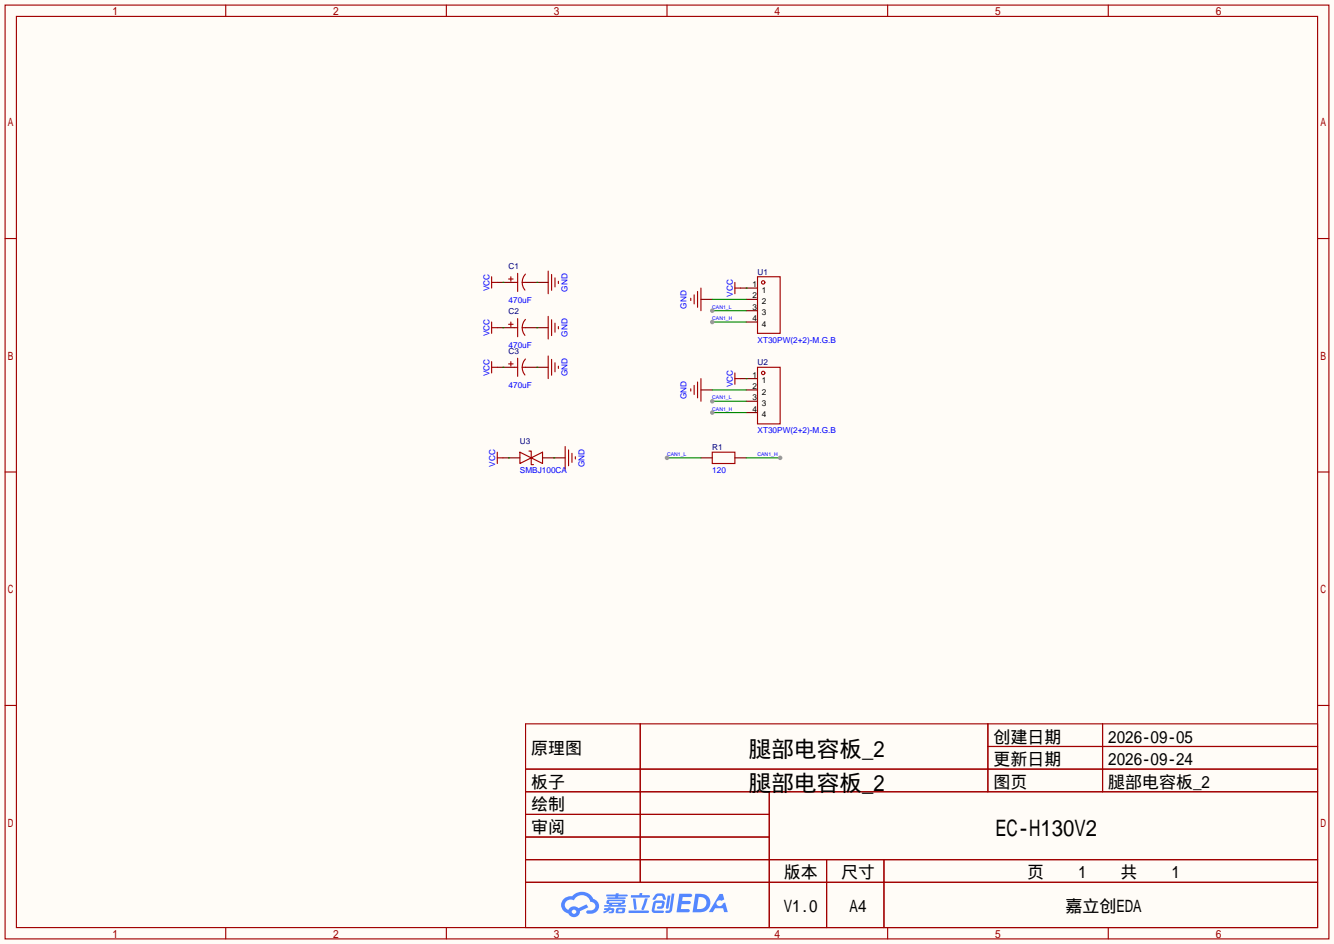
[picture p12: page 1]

VCC VCC

原理图 | 腿部电容板_2 | 创建日期 | 2026-09-05

更新日期 | 2026-09-24

板子 | 腿部电容板_2 | 图页 | 腿部电容板_2
绘制 | | EC-H130V2
审阅

V1.0 | A4 | 嘉立创EDA

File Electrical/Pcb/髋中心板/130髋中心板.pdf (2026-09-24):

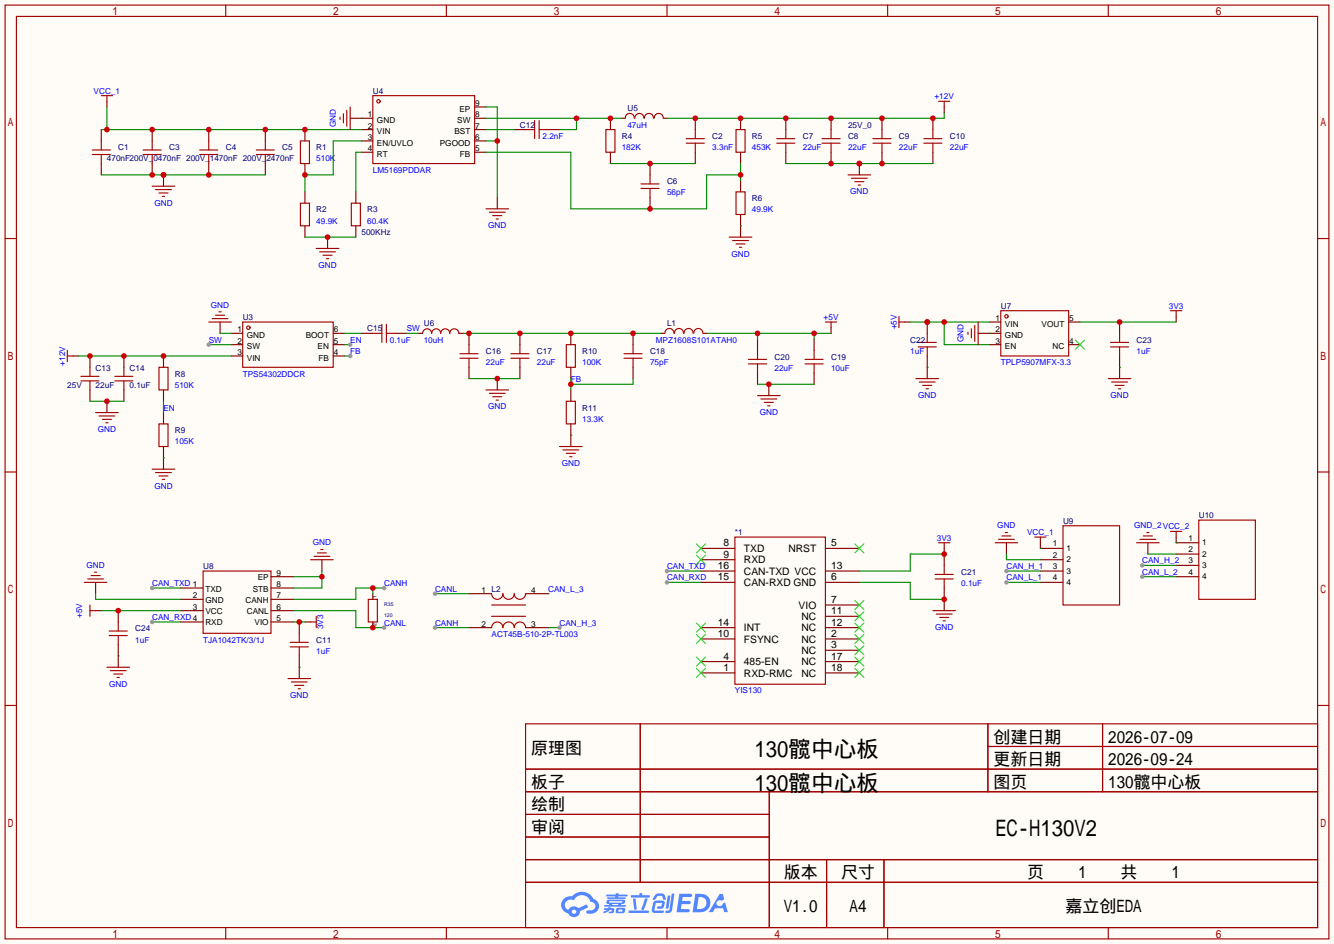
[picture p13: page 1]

原理图 | 130髋中心板 | 创建日期 | 2026-07-09

更新日期 | 2026-09-24

板子 | 130髋中心板 | 图页 | 130髋中心板
绘制 | | EC-H130V2
审阅

V1.0 | A4 | 嘉立创EDA

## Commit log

2026-09-27 Configure Git LFS for CAD models and meshes
    [3D_130髋中心板.step, 3D_胸腔电池安装板.step, 3D_腿部电容板_1.step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]
2026-09-27 Publish STEP assembly and Markdown wiring guide
    [EC-H130-V2_装配体.STEP]
